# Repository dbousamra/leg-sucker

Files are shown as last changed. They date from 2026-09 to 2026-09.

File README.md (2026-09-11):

# Leg Sucker — MVP 1

## What this is

Some people have arteries in their legs so narrowed that not enough blood gets in. The tissue
starves, ulcers open up and won't heal, and in bad cases the leg is amputated. The usual treatment —
squeezing the limb with compression stockings or cuffs — can't be used, because squeezing a leg
that's already short of arterial blood makes the inflow worse, and the skin is often too fragile to
touch at all.

The idea is to move blood **without touching the leg**: seal the limb in a rigid chamber and cycle
the air pressure around it in time with the heartbeat. Suck as the heart beats, so the arteries meet
less resistance from outside. Push gently between beats, to help fluid drain back out. A bellows
around the leg, breathing with the pulse.

That's unproven and a long way off. **This document is the first question underneath it: can a voice
coil generate useful pressure in a sealed chamber?** A speaker on a sealed PVC tube, and a gauge to
see what comes out.

No leg, no seal, no ECG, no human.

---

## Parts

| Item | What it does |
|---|---|
| [8" woofer, Jaycar CW2196](https://www.jaycar.com.au/woofer-speaker-driver-8-inch/p/CW2196) | **The actuator.** A speaker is a voice coil that already has a piston (the cone) and a flexible gas seal (the surround) built in |
| [100 mm PVC DWV pipe, 3 m](https://www.bunnings.com.au/holman-100mm-x-3m-pvc-dwv-pipe_p4770345) | The chamber. 85 mL of air per cm of length |
| [100 mm push-on cap](https://www.bunnings.com.au/search/products?q=Holman+100mm+PVC+DWV+Push+On+Cap) × 2 | Seals the far end. One gets drilled for the sensor port |
| [Deks 100 mm rubber joiner](https://www.bunnings.com.au/deks-100mm-pvc-to-pvc-rubber-joiner_p4730112) × 2 | Joins adaptor to pipe, and pipe to pipe — with hose clamps, so you can pull it apart to change the chamber volume |
| `cad/adaptor-spigot.stl` | Printed funnel taking the 220 mm driver down to the 110 mm pipe |
| [4 mm brass bulkhead barb](https://www.aliexpress.com/item/33041152234.html) | Passes through the end cap so the sensor can see chamber pressure. Nut clamps it, silicone seals it |
| [Clear silicone tube, OD5 × ID3 mm](https://www.aliexpress.com/item/1005008350652653.html) | Barb to sensor. Clear, so you can see if condensation collects |
| [MPXV7002DP sensor](https://www.aliexpress.com/item/1005007057842984.html) | Measures chamber pressure against room air. ±15 mmHg. **The one number this whole rig exists to produce** |
| [Raspberry Pi Pico 2](https://www.aliexpress.com/item/1005008058623788.html) | Generates the drive waveform, reads the sensor, streams CSV over USB |
| [IBT-2 / BTS7960 motor driver](https://www.aliexpress.com/item/1005009194435701.html) | Pushes current through the coil in both directions, at frequencies an audio amp can't reach |
| [2200 µF 35 V capacitor](https://www.aliexpress.com/item/1005011811368397.html) | Sits across the driver's supply and soaks up the energy the cone pushes back |
| [Resistor kit](https://www.aliexpress.com/item/1005011772534173.html) — you need 2 × 10 kΩ | Halves the sensor's 5 V output so it can't destroy the Pico's 3.3 V input |
| [830-point breadboard](https://www.aliexpress.com/item/1005003647931024.html) | Holds the divider and the sensor |
| [Dupont jumpers, 120 pc](https://www.aliexpress.com/item/1005002349042216.html) | Pico to driver logic pins and to the sensor |
| [18 AWG silicone cable, 3 m](https://www.aliexpress.com/item/1005009192506490.html) | Driver to speaker. Carries 3–5 A, so not jumper wire |
| [Spade connectors](https://www.jaycar.com.au/search?text=spade%20connectors) | Onto the speaker tabs |
| [Neutral-cure silicone](https://www.bunnings.com.au/search/products?q=neutral+cure+silicone+sealant) | Seats the barb and anything not solvent-welded |
| [PVC cement + priming fluid](https://www.bunnings.com.au/search/products?q=Protek+Type+N+PVC+Cement+Non+Pressure) | The PVC-to-PVC joints. Does **not** bond to PLA or PETG |
| [Two-part epoxy](https://www.bunnings.com.au/search/products?q=two+part+epoxy+resin) | Sealing the printed adaptor if it leaks through the layer lines |
| [M4 bolts + foam gasket](https://www.bunnings.com.au/search/products?q=M4+bolts) | Mounts the driver airtight to the adaptor |
| [Pipe saddle clips](https://www.bunnings.com.au/search/products?q=100mm+pipe+saddle+clip) × 2 | Holds the rig down. 29 N oscillating at 1 Hz will walk a 1 m pipe off the bench |
| [60 mL syringe](https://www.bunnings.com.au/search/products?q=60ml+syringe) | Injects a known volume for the leak test and to measure the chamber |

Plus a bench supply, a 3D printer, and a micro-USB cable.

---

## Build

**1. Print the adaptor** — `cad/adaptor-spigot.stl`. 245 mm flange, 182 mm driver cutout, tapering
to a 110 mm spigot. Print flange-down; the taper is 38° from vertical so it needs no support.

The front face has a scribed groove at the 212 mm bolt circle but **no bolt holes** — Jaycar don't
publish how many the driver has. Sit the driver on the groove, mark through its own flange, drill.

**2. Cut 800 mm of pipe.** Cap one end.

**3. Drill the end cap** for the bulkhead barb. Nut on the inside, silicone on the seat.

**4. Check the print holds air.** Blank off the spigot and pressurise. PETG with 5+ perimeters is
often fine; only brush it with epoxy if it actually weeps.

**5. Bolt the driver on** — cone facing *into* the tube, basket out in free air, foam gasket under
the flange.

That orientation matters. Mounted this way the funnel only clears the shallow dish of the cone.
Turned round, it would have to swallow the whole 92 mm-deep basket.

**6. Clamp the adaptor to the pipe** with a rubber joiner. Tighten both hose clamps. Nothing here is
glued — solvent cement dissolves PVC and does nothing to PETG, and you'll be pulling this apart
repeatedly to change volume.

**7. Bolt the rig down** with the saddle clips.

**8. Leak test.** Push air in with the syringe and watch the pressure. It should hold for at least
ten seconds. Find leaks now — a leaky tube looks exactly like a weak actuator.

**9. Measure the real chamber volume.** Don't calculate it: the adaptor alone adds 1.36 L, so 800 mm
of pipe is nearer 8 L than 6.7 L. Inject a known volume **slowly** and read the settled pressure:

```
V = 760 × injected_volume / ΔP        [litres, mmHg]
```

60 mL giving 8.9 mmHg means 5.1 L. Use that number everywhere afterwards.

---

## Wire

**Driver → IBT-2 → Pico**

| IBT-2 | Goes to |
|---|---|
| `B+` / `B−` | Bench supply, **with the 2200 µF capacitor across these pins** (stripe to `B−`) |
| `M+` / `M−` | Speaker terminals, 18 AWG cable |
| `VCC` | Pico `3V3` (pin 36) |
| `GND` | Pico `GND` **and** supply ground |
| `R_EN`, `L_EN` | Both to Pico `3V3` |
| `RPWM` | `GP16` |
| `LPWM` | `GP17` |

PWM one and hold the other low to push the cone; swap to pull. **Never drive both high** — that
shorts the supply through the bridge.

**Sensor → Pico**

- Sensor power: `VBUS` (pin 40) and `GND`
- Sensor output → **2:1 divider**, two 10 kΩ resistors → `GP26`
- **Only one sensor port goes to the chamber.** The other stays open to room air — that's what makes
  it differential

**Four things that will cost you an evening**

- **Motor driver, not an audio amp.** Audio amps block everything below ~20 Hz. You're running at
  1 Hz, so one would throw away almost everything and make the rig look dead.
- **The divider isn't optional.** The sensor swings to 4.5 V; the Pico's ADC stops at 3.3 V.
- **Keep the motor circuit off the breadboard.** It carries 3–5 A; breadboards manage about 1 A
  before the contacts cook. Screw terminals and proper cable for that loop.
- **Star-ground at the IBT-2.** Run motor ground straight back to the driver, not daisy-chained
  through the breadboard, or the switching noise lands in your pressure trace.

---

## Run

Set the supply to **12 V with a 4 A current limit** before anything is connected. Verify with a
meter.

**1. Test the driver with the speaker on the bench, out of the chamber.** Slow sine, low amplitude,
watch the cone. If it fails here it's electrical — you don't want to be wondering whether it's a
leak.

**2. Wind the amplitude up until you hear the coil bottom out** — a dull click. Stay below that
level, and note it. **That's your first real measurement of Xmax**, which no datasheet gave you, and
every predicted pressure below scales off it.

**3. Bolt it to the chamber** and repeat at low amplitude. Pressure should appear immediately.

**4. Start with a long chamber and work down.** At 15 L you need only 1.5–2 A. At 6.7 L you need
3–5 A, near your supply's ceiling — and if the result disappoints you won't know whether it's
current limiting, a leak, or the driver.

Then measure:

- **Slow sine, ~1 Hz** — how many mmHg? That's the headline number
- **Sweep 0.5 to 20 Hz** — find where it falls off
- **Fast step** — flip negative to positive as fast as you can. 50 ms is the target, the useful
  window in a heartbeat
- **Add pipe** — pressure should drop in proportion. That's the scaling law that predicts a
  leg-sized chamber

**Don't hold a steady offset for long.** Below resonance the coil behaves like a plain resistor and
pulls current while doing nothing, so it heats. Short bursts only.

---

## What to expect

The driver sweeps about **176 mL** per cycle (220 cm² cone, ±4 mm).

| Chamber | Expected swing |
|---:|---|
| 2 L | ±33 to ±47 mmHg |
| 5 L | ±13 to ±19 mmHg |
| 6.7 L | ±10 to ±14 mmHg |
| 10 L | ±6.7 to ±9.4 mmHg |
| 15 L | ±4.5 to ±6.2 mmHg |
| 45 L (real leg chamber) | ±1.5 to ±2.1 mmHg |

Each range spans slow compression (heat escapes) to fast (it doesn't). Which end you land on is one
of the things this rig measures.

**Success** is a clean, repeatable swing of a few mmHg that behaves as expected when you change
amplitude and tube length.

**The 45 L row is the real finding.** Not a failure — the scaling law being honest. A leg chamber
needs roughly 1 litre of swept volume, about 6× this driver. Proving the physics at 5 L is what
justifies spending real money on that actuator.

---

## Later

Thigh seal · ECG gating · measuring anything physiological · anything involving a person.

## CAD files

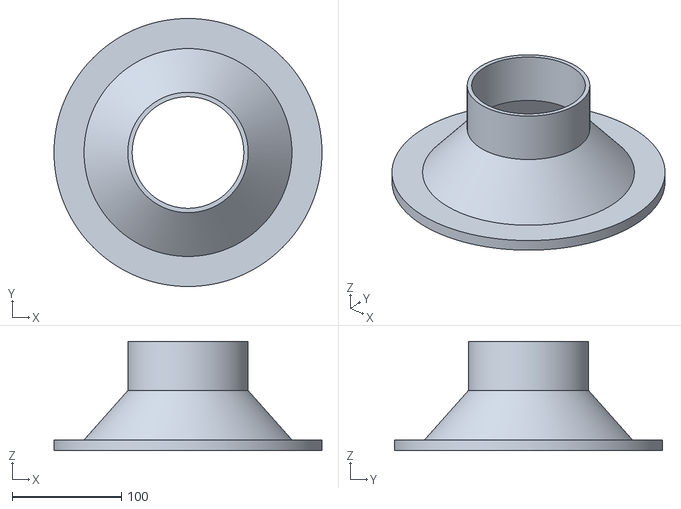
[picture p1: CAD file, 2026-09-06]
cad/adaptor-spigot.stl
245.0 x 245.0 x 100.0

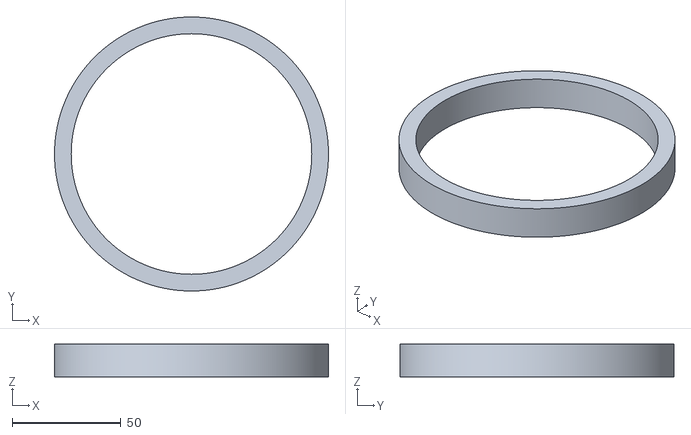
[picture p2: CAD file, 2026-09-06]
cad/pipe-fit-test-ring.stl
126.0 x 126.0 x 15.0

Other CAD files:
cad/adaptor-socket.stl

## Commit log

2026-09-06 Initial commit: leg-sucker MVP 1 build plan
    A bench rig to answer one question: can a voice coil generate useful
    positive and negative pressure in a sealed chamber?
    - README.md: the MVP build plan — rationale, BOM (~AU$227), build steps,
    wiring, and test procedure. Speaker driver on a sealed DN100 PVC tube,
    read by an MPXV7002DP into a Raspberry Pi 4 via an ADS1115.
    - CLAUDE.md: project context, the corrected polytropic gas relation,
    actuator sourcing conclusions, and SensorMedics 3100A findings.
    Claude-Session: https://claude.ai/code/session_01DC7wBsFFCWE4J3njd7Kr5q
2026-09-06 Add printable adaptor STL, and correct two build errors it exposed
    cad/adaptor.py generates both meshes parametrically (pure Python, no CAD
    dependency). Both verified watertight with outward normals.
    - cad/adaptor.stl — 245 mm flange, 182 mm driver cutout, tapering to a
    45 mm socket over DN100 pipe. 100 mm long, ~460 cm3 solid.
    - cad/pipe-fit-test-ring.stl — few-gram print to check the socket fits
    real pipe before committing to the big one.
    Two corrections to the build steps:
    - The adaptor cannot be solvent welded. PVC cement works by dissolving
    PVC and does nothing to PLA or PETG. The socket is a slip fit sealed
    with silicone instead.
    - It has to be a funnel, not a flat plate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
    [adaptor.stl, pipe-fit-test-ring.stl]
2026-09-06 Make every joint reversible with rubber joiners instead of glue
    The test plan works by changing chamber volume, so a rig that can't be
    taken apart can only be measured once. Swaps the solvent-weld repair
    coupling for Deks 100mm PVC-to-PVC rubber joiners ($10.50 each) — a
    rubber sleeve with two hose clamps, undone in seconds.
    - cad/adaptor-spigot.stl (new, recommended): ends in a 110 mm spigot at
    pipe OD so the joiner clamps over both sides. 1.36 L dead volume.
    - cad/adaptor-socket.stl: the previous socket design, kept as the
    no-external-hardware option. 1.03 L, but needs a ~110 mm O-ring and is
    fiddlier to separate.
    Also clarifies that the epoxy was always a coating for print poros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
    [adaptor-socket.stl, adaptor-spigot.stl, adaptor.stl]
2026-09-09 Add wiring and connectors to the BOM
    The BOM listed every board and fitting but no wire, which would have
    blocked assembly. Adds speaker cable, spade connectors and jumper leads.
    Also warns against running the motor circuit through a breadboard —
    it carries 3-5 A and breadboards are good for about 1 A.
    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
2026-09-09 Switch the controller from Raspberry Pi 4 to Pico 2
    The Pi 4 was chosen for familiarity, but the user doesn't own one and a
    Pico is a tenth of the price and the better tool here:
    - Built-in ADCs, so the ADS1115 becomes optional rather than required
    - Deterministic timing, which the 50 ms step test and later ECG gating
    both need; a Linux host would have jittered
    Rewires to GP16/GP17 for PWM (channels A and B of one slice, so they
    share a carrier with independent duty) and GP26 for the sensor. The
    10k divider stays either way — the sensor swings to 4.5 V on a 5 V rail
    and the Pico's ADC stops at 3.3 V.
    ADS1115 kept in the BOM at $2 as a diagnostic fallback: if the trace
    looks noisy, swa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
2026-09-09 Add the parts and sequence needed to actually reach first light
    Three things missing from the BOM that would each have stopped the
    build: a micro-USB cable (the Pico needs one and most people only have
    USB-C now), a breadboard for the divider, and something to hold the rig
    down — 29 N oscillating at 1 Hz will walk a 1 m pipe off the bench.
    Adds a First power-up sequence that tests the driver with the speaker
    out of the chamber before sealing it, so an electrical fault can't be
    mistaken for a leak. Listening for the coil bottoming out also gives the
    first real measurement of Xmax, which no datasheet supplied.
    Also documents two easy mistakes: leaving both sensor ports connected,
    and daisy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
2026-09-09 Update BOM to match the actual AliExpress order
    Breadboard, resistor kit, capacitor, bulkhead barb and silicone tube now
    sourced from AliExpress at a fraction of local prices - the whole
    electronics side is AU$57 in one order.
    Records the specific parts chosen: 4 mm brass bulkhead barb through the
    end cap, and OD5xID3mm clear tube (3 mm ID grips the sensor's ~3.2 mm
    barb and still stretches onto the 4 mm bulkhead; clear so condensation
    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
2026-09-11 Correct BOM to real prices and actual suppliers
    The previous BOM quoted AliExpress "new shopper" prices seen while
    signed out. Those evaporate at checkout for an existing account — the
    Pico alone went $5.94 -> $17.09. Every price here is now what the
    account actually pays, and the doc says so, so nobody plans around the
    phantom numbers again.
    Restructured into one AliExpress order (~$131 delivered) and a local run
    (~$190). Adds the two items that were missing and would have blocked
    assembly: a 120-piece Dupont jumper set, and 3 m of 18 AWG silicone
    cable for the speaker run, which carries 3-5 A and cannot be jumper
    wire.
    Total moves from ~$250 to ~$320.
    Claude-Session: https://claude.ai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
2026-09-11 Rewrite README as a build sequence
    Cuts it from 416 lines to ~180. The doc had accumulated the reasoning
    behind each decision alongside the instructions; the reasoning belongs
    in CLAUDE.md, which already carries it.
    - Parts is now one flat table of item and what it does, no supplier
    split or prices — those decisions are made
    - Build, Wire and Run are numbered steps
    - The separate Power supply, Notes, reversibility and actuator-rationale
    sections are gone; the parts of them that prevent failure are folded
    into the step they apply to
    Nothing load-bearing was dropped: motor driver not audio amp, the
    divider, the bulk capacitor, star grounding, one sensor port only,
    4 A limit, leak tes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
2026-09-23 feat: add MicroPython firmware scaffold and justfile dev loop for Pico 2
